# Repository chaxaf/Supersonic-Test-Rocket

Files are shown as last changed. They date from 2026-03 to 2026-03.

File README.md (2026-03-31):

# Hermes II Avionics Redesign

Semester project completed with the EPFL Rocket Team in 2022.

Hermes II is a compact avionics architecture developed for a small experimental rocket intended for validation flights and data generation. The project focused on redesigning the electronics of the original Hermes platform into a smaller, more modular system with telemetry, GPS, multiple sensor boards, and improved integration inside the rocket.

## Project summary

The avionics stack is built around one main PCB and three auxiliary PCBs placed in different parts of the rocket:

- **Main PCB** in the avionics bay
- **Nosecone PCB** for total pressure and wall temperature
- **Static port PCB** for static pressure and wall temperature
- **Load cell PCB** for thrust measurement signal conditioning

The design integrates:
- Teensy 3.5 microcontroller
- GPS
- XBee telemetry
- IMU and accelerometer
- pressure sensors
- thermocouple interfaces
- load cell instrumentation amplifier
- battery management and power regulation

## System overview

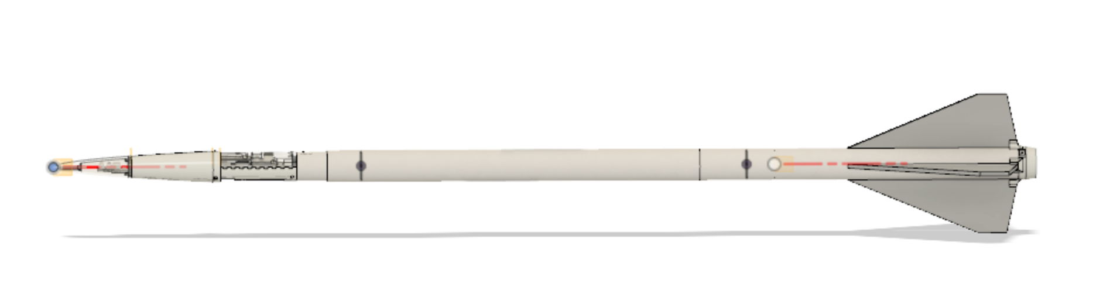
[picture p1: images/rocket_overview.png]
Rocket overview


**Source in repository:** `docs/Hermes_Presentation.pptx`

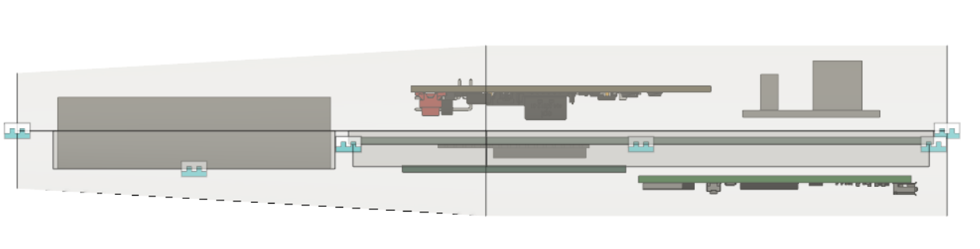
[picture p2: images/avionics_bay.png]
Avionics bay


## Main PCB

The main board had to fit inside a very constrained avionics bay while interfacing with the GPS, telemetry radio, IMU, pressure sensors, thermocouples, Altimax, Wildhorn sensor board, and auxiliary boards. It uses a 4-layer stack-up with dedicated ground and power planes.

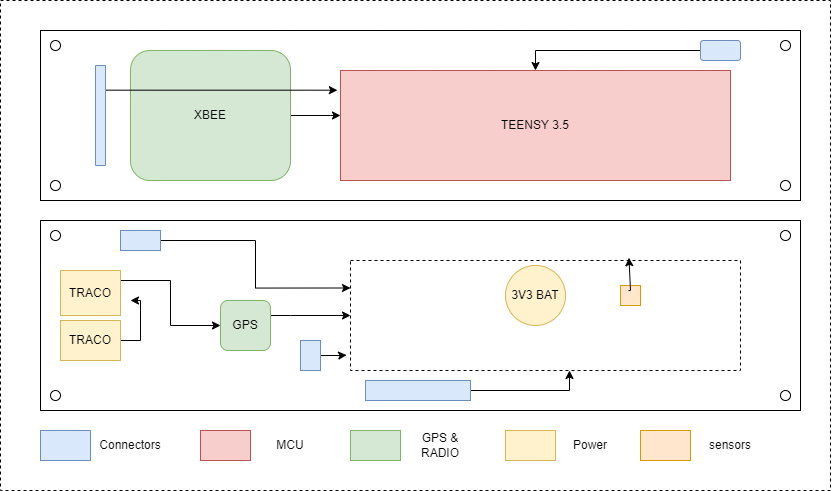
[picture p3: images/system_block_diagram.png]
System block diagram


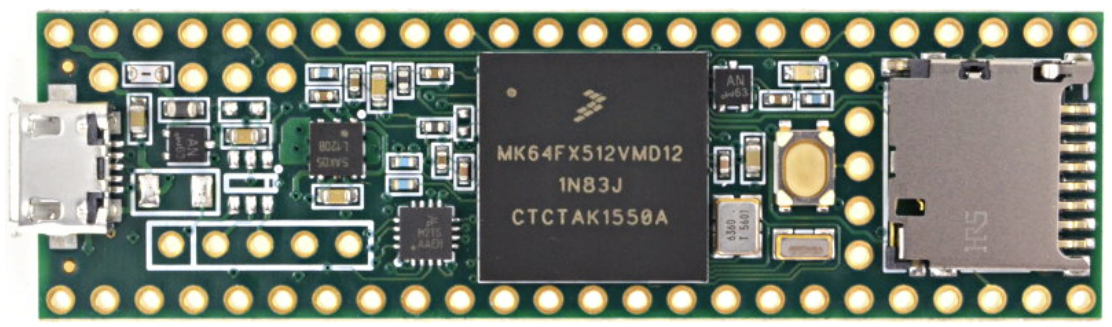
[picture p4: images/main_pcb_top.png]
Main PCB top


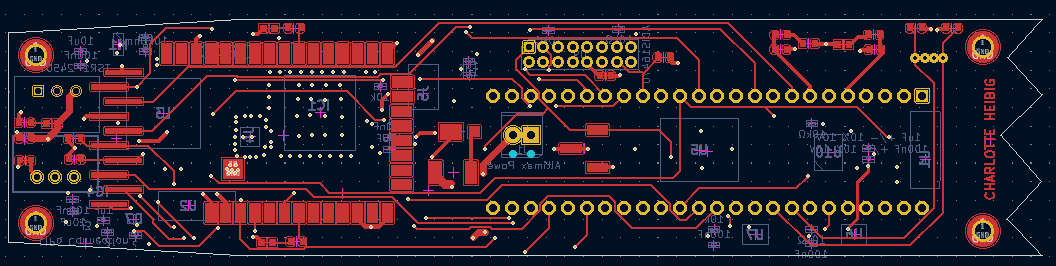
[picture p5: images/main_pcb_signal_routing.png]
Main PCB routing


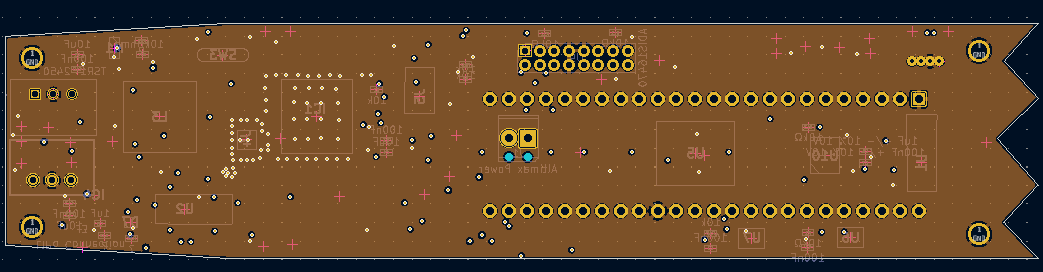
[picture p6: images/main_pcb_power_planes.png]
Main PCB power planes


## GPS layout constraints

One of the most layout-sensitive parts of the board was the GPS section, especially antenna routing and the controlled-impedance microstrip connection.

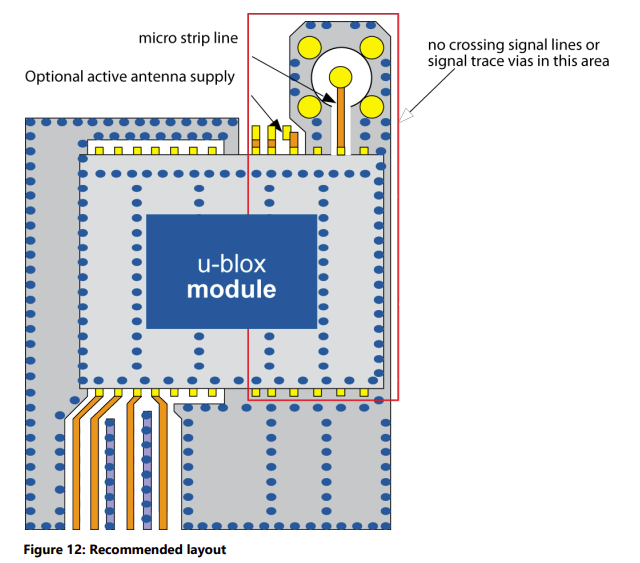
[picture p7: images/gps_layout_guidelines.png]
GPS layout


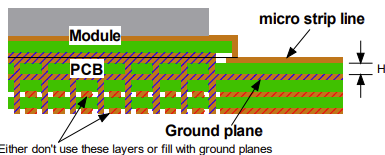
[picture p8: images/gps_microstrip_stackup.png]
GPS microstrip stackup


## Auxiliary PCBs

### Nosecone PCB
Measures total pressure and wall temperature.

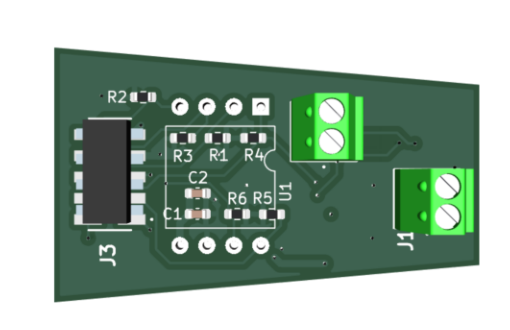
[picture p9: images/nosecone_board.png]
Nosecone PCB


### Static port PCB
Measures static pressure and wall temperature.

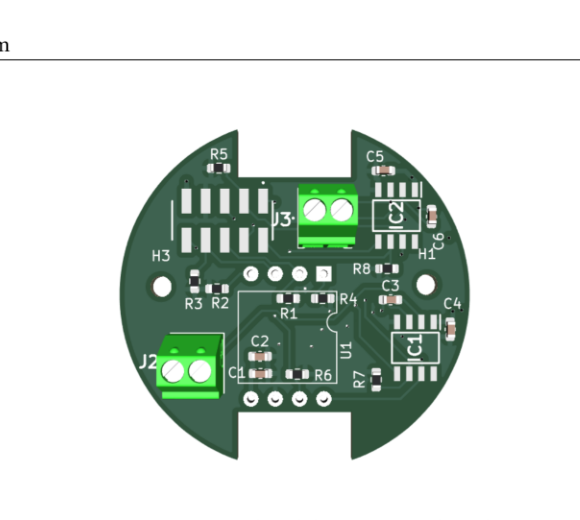
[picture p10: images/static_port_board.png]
Static port PCB


### Load cell PCB
Conditions the load cell signal used for thrust measurement.

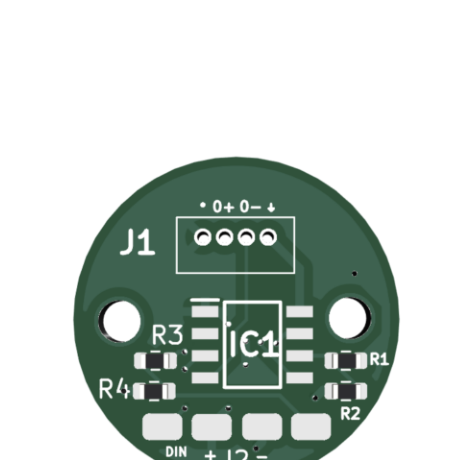
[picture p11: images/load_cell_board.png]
Load cell PCB


## Main technical points

- Compact avionics redesign for a constrained rocket airframe
- Separation of avionics into one main PCB and three auxiliary PCBs
- Integration of telemetry and GPS
- Pressure, temperature, acceleration, and inertial sensing
- Load cell instrumentation for thrust measurements
- 4-layer PCB design under mechanical, thermal, and routing constraints
- Manufacturing through a combination of external PCB assembly and manual soldering

## Results

According to the final presentation, the following subsystems were functional during project testing:

- GPS worked outdoors
- telemetry radio worked
- thermocouples worked
- pressure sensors, IMU, and Altimax were functional
- the accelerometer worked after replacing a faulty capacitor

Main issues and remaining work included:

- power supply malfunction
- some MAX31855 thermocouple interfaces failed
- connector orientation errors that were later corrected
- remaining validation work for the load cell amplifier and some Wildhorn sensor software

See slides **“RESULTATS”** and **“CONCLUSION”** in `docs/Hermes_Presentation.pptx`.

## Repository structure

```text
Hermes-II-GitHub/
├── README.md
├── .gitignore
├── docs/
│   ├── Hermes_Presentation.pptx
│   └── report.pdf
├── images/
│   ├── rocket_overview.png
│   ├── avionics_bay.png
│   ├── system_block_diagram.png
│   ├── main_pcb_top.png
│   ├── main_pcb_bottom.png
│   ├── main_pcb_signal_routing.png
│   ├── main_pcb_power_planes.png
│   ├── gps_layout_guidelines.png
│   ├── gps_microstrip_stackup.png
│   ├── nosecone_board.png
│   ├── static_port_board.png
│   └── load_cell_board.png
└── hardware/
    ├── main_pcb/
    ├── nosecone_pcb/
    ├── static_port_pcb/
    └── load_cell_pcb/
```

## Opening the hardware files

The hardware design files are provided in KiCad project format. Open the corresponding `.kicad_pro` file in each hardware subfolder.

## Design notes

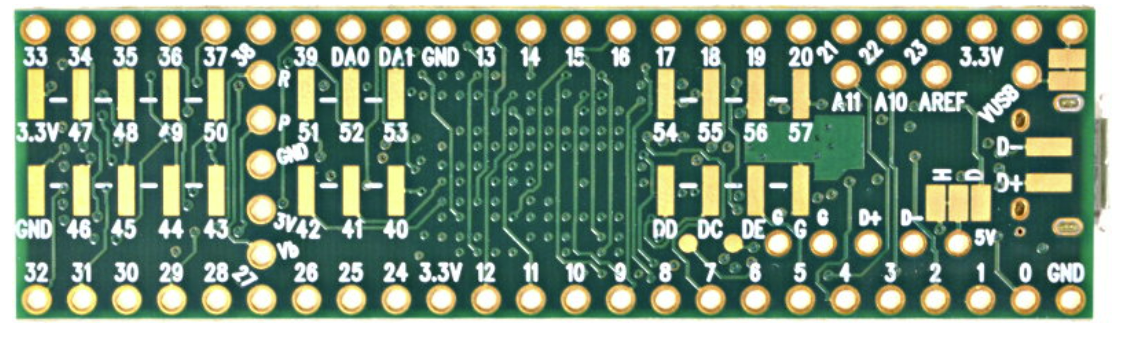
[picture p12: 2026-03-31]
images/main_pcb_bottom.png

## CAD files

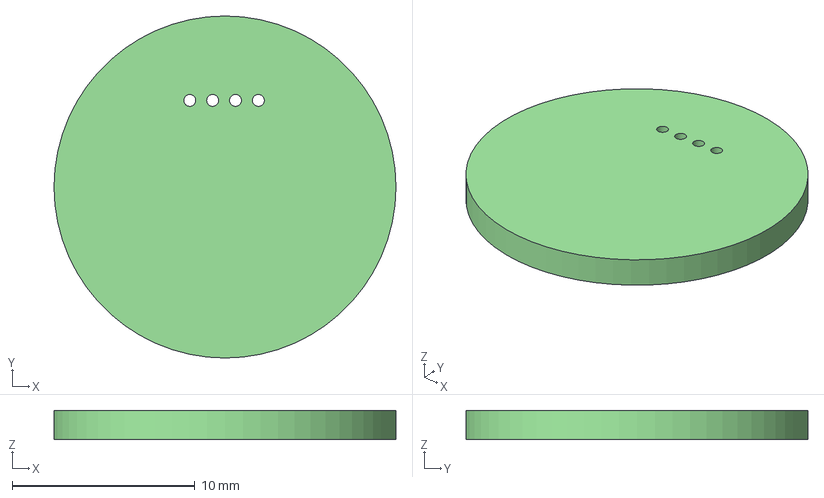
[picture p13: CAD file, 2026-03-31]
hardware/load_cell_pcb/load cell.step
18.7 x 18.7 x 1.60 mm

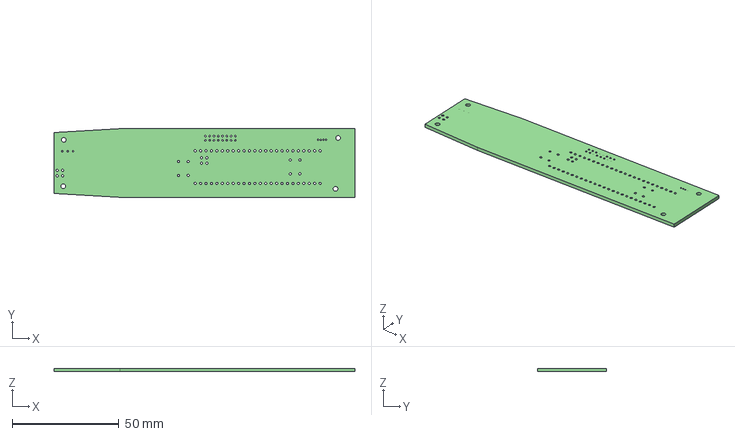
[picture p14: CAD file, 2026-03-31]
hardware/main_pcb/PCB_v1.step
140.8 x 32.1 x 1.60 mm

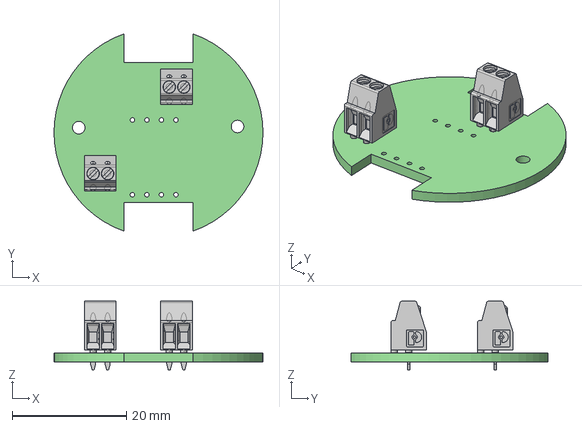
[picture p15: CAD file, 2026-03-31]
hardware/static_port_pcb/nosecone.step
36.6 x 34.6 x 12.0 mm
nosecone PCB

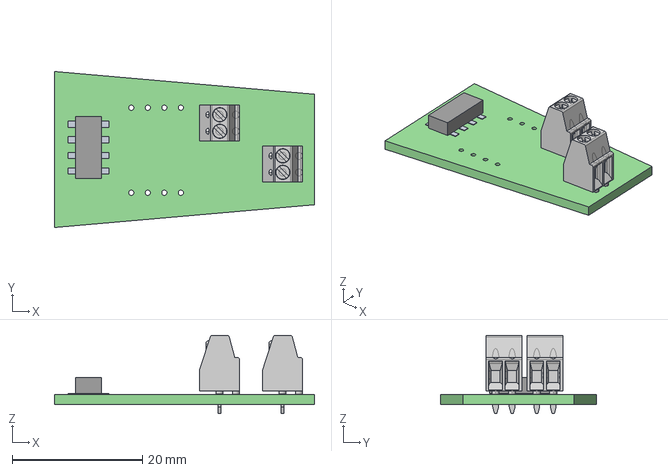
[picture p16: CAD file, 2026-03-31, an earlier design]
hardware/nosecone_pcb/nosecone.step
40.0 x 24.0 x 12.0 mm
_autosave-nosecone PCB

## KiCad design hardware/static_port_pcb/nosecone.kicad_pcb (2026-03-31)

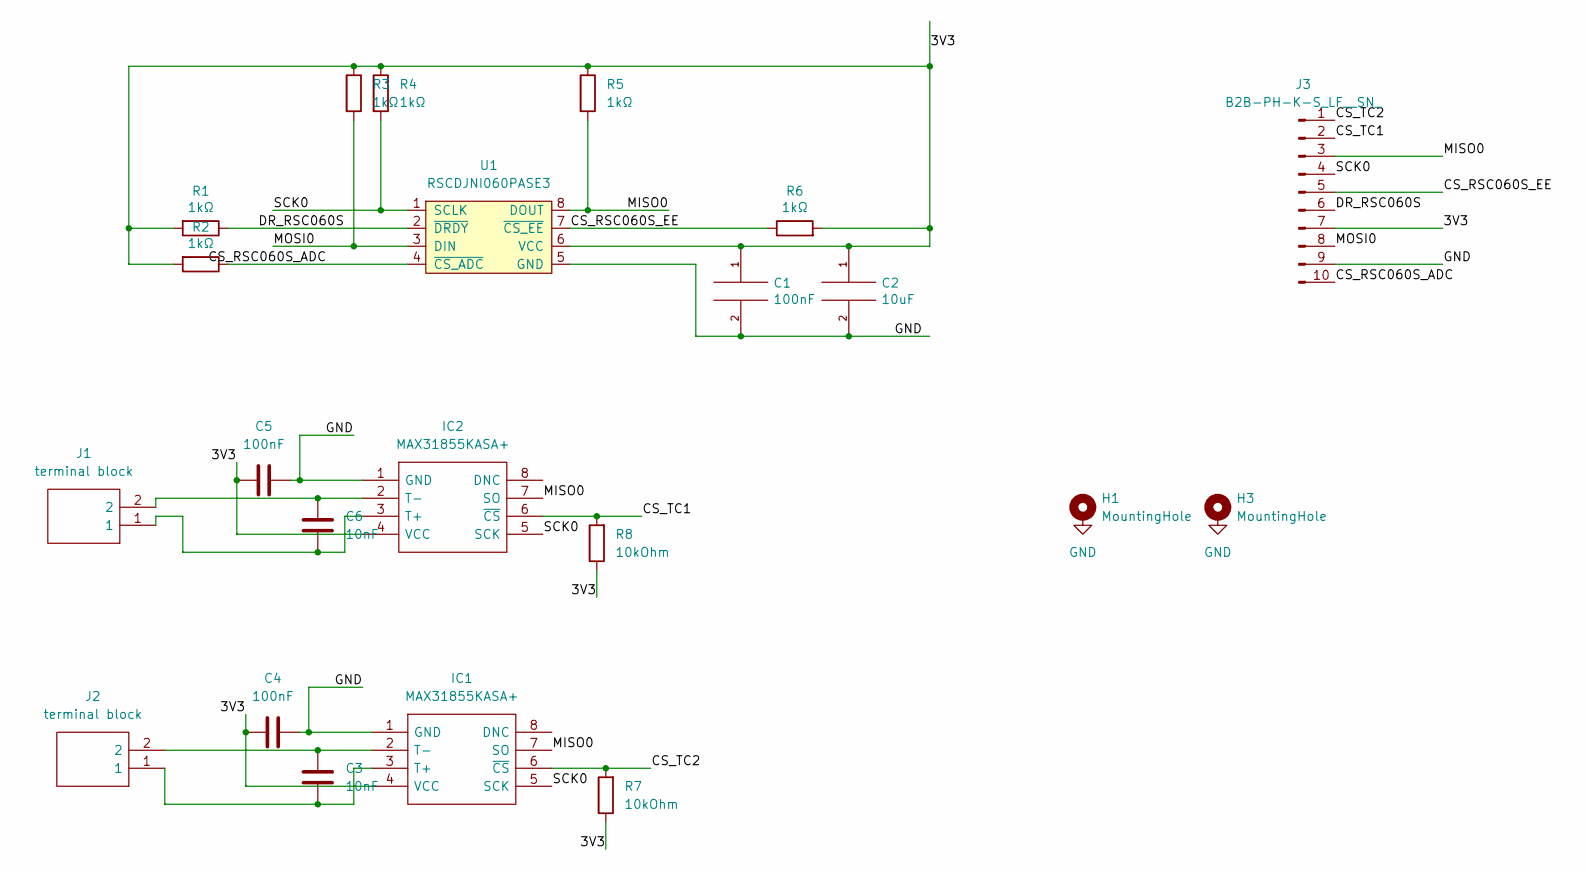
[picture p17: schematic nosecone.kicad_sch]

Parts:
C1, C4, C5: 100nF; C_0603_1608Metric
C2: 10uF; C_0603_1608Metric
C3, C6: 10nF; C_0603_1608Metric
H1, H3: MountingHole; MountingHole_2.2mm_M2
IC1, IC2: MAX31855KASA+; SOIC127P600X175-8N; Manufacturer_Part_Number MAX31855KASA+; Mouser Part Number 700-MAX31855KASA+
J1, J2: terminal block; Manufacturer_Part_Number 1725656; Mouser Part Number 651-1725656
J3: B2B-PH-K-S_LF__SN_; 57202G5205LF
R1, R2, R3, R4, R5, R6: 1kΩ; R_0603_1608Metric
R7, R8: 10kOhm; R_0603_1608Metric
U1: RSCDJNI060PASE3; DIP-8_W13.08mm

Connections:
/3V3: C1.1, C2.1, C4.2, C5.2, IC1.4 (VCC), IC2.4 (VCC), J3.7, R1.2, R2.2, R3.1, R4.1, R5.1, R6.2, R7.1, R8.1, U1.6 (VCC)
/CS_RSC060S_ADC: J3.10, R2.1, U1.4 (~CS_ADC)
/CS_RSC060S_EE: J3.5, R6.1, U1.7 (~CS_EE)
/CS_TC1: IC2.6 (~CS), J3.2, R8.2
/CS_TC2: IC1.6 (~CS), J3.1, R7.2
/DR_RSC060S: J3.6, R1.1, U1.2 (~DRDY)
/MISO0: IC1.7 (SO), IC2.7 (SO), J3.3, R5.2, U1.8 (DOUT)
/MOSI0: J3.8, R3.2, U1.3 (DIN)
/SCK0: IC1.5 (SCK), IC2.5 (SCK), J3.4, R4.2, U1.1 (SCLK)
GND: C1.2, C2.2, C4.1, C5.1, IC1.1 (GND), IC2.1 (GND), J3.9, U1.5 (GND)
unnamed: C3.1, IC1.3 (T+), J2.1
unnamed: C3.2, IC1.2 (T-), J2.2
unnamed: C6.1, IC2.3 (T+), J1.1
unnamed: C6.2, IC2.2 (T-), J1.2

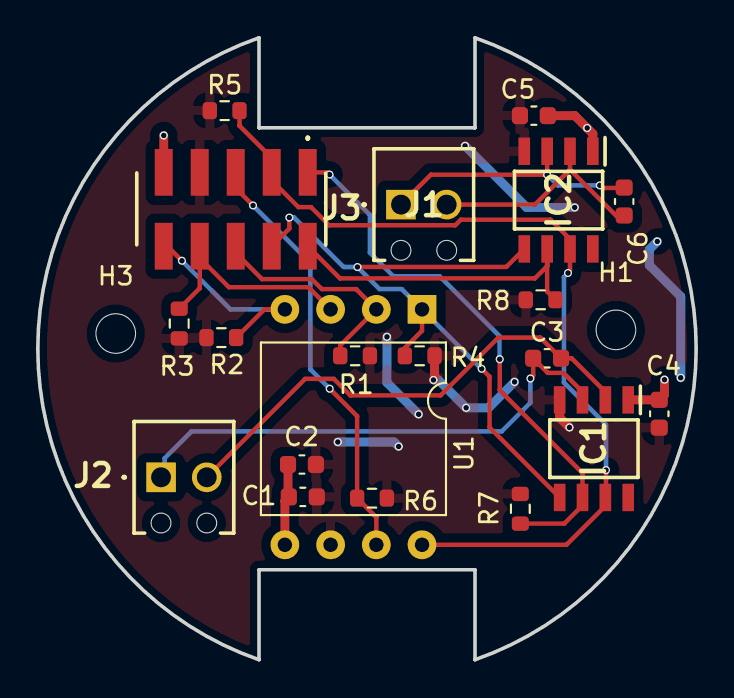
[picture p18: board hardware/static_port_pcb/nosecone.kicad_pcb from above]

Board: 2 copper layers, 36.6 x 34.6 mm, 22 parts (0 on the bottom side), 14 nets.

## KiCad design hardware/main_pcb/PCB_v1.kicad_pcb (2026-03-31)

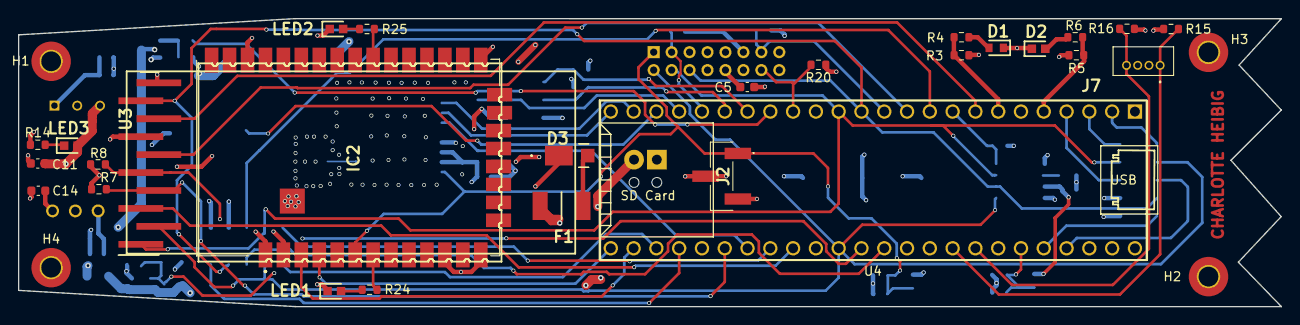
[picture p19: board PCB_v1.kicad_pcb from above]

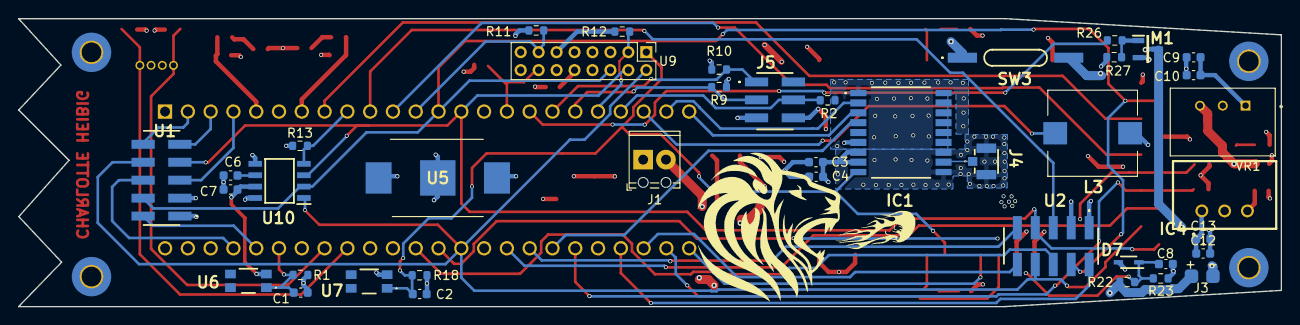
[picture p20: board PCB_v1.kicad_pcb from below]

Board: 4 copper layers, 140.8 x 32.1 mm, 72 parts (41 on the bottom side), 57 nets.

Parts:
C1, C2, C3, C5, C10, C11, C13, C14: 100nF; C_0603_1608Metric
C4, C9, C12: 10uF; C_0603_1608Metric
C6: 1uF +/- 10% 10V; C_0603_1608Metric
C7: 100nF +/- 10% 10V; C_0603_1608Metric
C8: 1uF; C_0603_1608Metric
D1: White LED; LEDC1608X45N
D2: Red LED; LEDC1608X80N
D3: D_Schottky; V8PAN50M3I
D7: BZX584C3V3-G3-08; SOD2513X110N
F1: MINIASMDC150F_12-2; MINISMDC050F2
H1, H2, H3, H4: Board_Hole; MountingHole_2.2mm_M2_Pad_TopBottom
IC1: MAX-7C-0; MAX7C0
IC2: XB8X-DMUS-001; XBP9XDMRS001
IC4: TSR_0.5-2433; TSR-0.5-2433
J1: Altimax Power; TerminalBlock_Phoenix_MPT-0,5-2-2.54_1x02_P2.54mm_Horizontal
J2: 0878980304
J3: LiPo Connection; pad2
J4: CONUFL001-SMD-T; CONUFL001-SMD
J5: 57202G5203LF
J7: 1734598-4; 17345984
L3: SMI-1027-T-5V-R; SMI1027T5VR
LED1, LED2, LED3: 150060GS75000; LEDC1608X80N
M1: MNMOS; SOT95P237X112-3N
R1, R4, R6, R11, R12, R13, R20: 10kΩ; R_0603_1608Metric
R2, R9, R10, R15, R16, R18: 10k; R_0603_1608Metric
R3: 100Ω; R_0603_1608Metric
R5: 24Ω; R_0603_1608Metric
R7, R8, R27: 10kOhm; R_0603_1608Metric
R14: 10K; R_0603_1608Metric
R22, R23: ?; R_0603_1608Metric
R24, R25: 24; R_0603_1608Metric
R26: R; R_0603_1608Metric
SW3: MISM7R610
U1, U2: 57202G5205LF
U3: 1-2842102-0; HUSRSP10W50P200_2000X200X550P
U4: Teensy3.5; Teensy35_36_exterior_pins_only
U5: 3030
U6, U7: switch; RKC2SJF170SMTRLFS
U9: ADIS16470; PinHeader_2x08_P2.00mm_Vertical
U10: AIS1120SXTR; SOIC127P600X175-8N
VR1: TSR1-2450; CONV_TSR1-2450

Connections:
+3V3: C2.1, C3.1, C4.1, C5.1, C7.1, C14.1, IC1.7 (VCC_IO), IC1.8 (VCC), IC2.2 (VCC), IC4.3 (+VOUT), J5.6, R7.1, R8.1, R12.1, R13.1, R15.2, R16.2, R18.1, U1.3, U2.3, U3.7, U6.3, U9.10 (VDD), U9.11 (VDD), U9.12 (VDD), U10.7 (VDD)
+5V: C11.1, C12.1, C13.1, IC4.1 (+VIN), J7.3, LED3.2, U4.53 (Vin), VR1.3 (+VOUT)
/MISO0: U1.7, U2.7, U3.1, U4.14 (12_MISO0), U9.4 (DOUT), U10.3 (SDO)
/MOSI0: U1.4, U2.4, U3.9, U4.13 (11_MOSI0), U9.6 (DIN), U10.2 (SDI)
/RTC_supply: IC1.6 (V_BCKP), J2.2, U5.1, U5.3
/SCK0: U1.8, U2.8, U3.2, U4.40 (13_SCK0_LED), U9.2 (SCLK), U10.1 (SCL)
/aux1: J5.3, R9.2, U4.19 (27_RX1_SCK0)
/aux2: J5.1, R10.2, U4.18 (26_TX1_SCL2)
/aux3: J5.4, R2.1, U4.21 (29_PWM_CAN0TX_Touch)
/bat_voltage: C8.2, D7.1, R22.2, R23.1, U4.41 (14_A0_PWM_SCK0)
/button1: C1.1, R1.1, U4.48 (21_A7_PWM_CS0_MOSI1), U6.1
/buzzer_input: L3.1, U4.22 (30_PWM_CAN0RX_Touch)
/cs_acc: R13.2, U4.9 (7_RX3_MOSI0_SCL0), U10.4 (CS)
/cs_adis: R12.2, U4.20 (28_MOSI0), U9.3 (CS)
/cs_pressure_adc_1: U1.2, U4.49 (22_A8_PWM_Touch)
/cs_pressure_adc_2: U2.2, U4.33 (36_A17_PWM)
/cs_pressure_ee_1: U1.5, U4.4 (2_PWM)
/cs_pressure_ee_2: U2.5, U4.10 (8_TX3_MISO0_SDA0)
/cs_tc1: U1.9, U4.3 (1_TX1_MISO1_Touch)
/cs_tc2: U1.10, U4.2 (0_RX1_MOSI1_Touch)
/cs_tc3: U2.9, U4.37 (A21_DAC0)
/cs_tc4: U2.10, U4.32 (35_A16_PWM)
/dr_adis: R11.2, U4.12 (10_PWM_TX2_CS0), U9.13 (DR)
/dr_pressure_1: U1.6, U4.50 (23_A9_PWM_Touch)
/dr_pressure_2: U2.6, U4.42 (15_A1_CS0_Touch)
/enable_gnd: R26.1, U4.17 (25)
/gp0_spi: U3.3, U4.38 (A22_DAC1)
/gp3_spi: U3.8, U4.8 (6_PWM)
/gp4_spi: U3.6, U4.11 (9_PWM_RX2_CS0)
/led1: R3.2, R4.1, U4.7 (5_PWM_TX1_MISO1)
/led2: R5.1, R6.2, U4.5 (3_PWM_CAN0TX_SCL2)
/load_minus: J7.1, R15.1, U4.45 (18_A4_SDA0_Touch)
/load_plus: J7.4, R16.1, U4.46 (19_A5_SCL0_Touch)
/nReset: C2.2, IC1.9 (RESET_N), IC2.6 (~RESET), J2.1, R18.2, U7.1, U9.1 (RST)
/rx_ublox: IC1.3 (RXD), U4.24 (32_A13_TX4_SCK1)
/rx_xbee: IC2.4 (DIN/DIO14/~CONFIG), U4.30 (33_A14_TX5_CAN1TX_SCL0)
/scl_i2c: R8.2, U3.5, U4.34 (37_A18_PWM_SCL1)
/sda_i2c: R7.2, U3.4, U4.35 (38_A19_PWM_SDA1)
/sync_adis: R20.2, U4.16 (24), U9.14 (SYNC)
/timepulse_ublox: IC1.4 (TIMEPULSE), U4.36 (39_A20)
/tx_ublox: IC1.2 (TXD), U4.23 (31_A12_RX4_CS1)
/tx_xbee: IC2.3 (DIO13/DOUT), U4.31 (34_A15_RX5_CAN1RX_SDA0)
GND: C1.2, C3.2, C4.2, C5.2, C6.2, C7.2, C8.1, C9.2, C10.2, C11.2, C12.2, C13.2, C14.2, D1.1 (K), D2.1 (K), D7.2, H1.1, H2.1, H3.1, H4.1, IC1.1 (GND_1), IC1.10 (GND_2), IC1.12 (GND_3), IC2.1 (GND_1), IC2.11 (GND_2), IC2.13 (GND_3), IC2.22 (GND_4), IC2.35 (GND_5), IC2.38 (GND_6), IC4.2 (GND), J2.3, J4.2 (GND_1), J4.3 (GND_2), J5.5, J7.2, L3.2, LED1.1, LED2.1, M1.2 (S), R1.2, R2.2, R4.2, R6.1, R9.1, R10.1, R11.1, R14.2, R20.1, R23.2, R27.2, SW3.1 (A), U1.1, U2.1, U3.10, U4.1 (GND), U4.39 (GND), U5.2, U7.3, U9.7 (GND), U9.8 (GND), U9.9 (GND), U10.5 (GND), U10.8 (MP), VR1.2 (GND)
unnamed: C6.1, U10.6 (VREG)
unnamed: C9.1, C10.1, D3.1 (K), VR1.1 (+VIN)
unnamed: D1.2 (A), R3.1
unnamed: D2.2 (A), R5.2
unnamed: D3.2 (A), F1.2
unnamed: F1.1, J1.2, J3.2, R22.1
unnamed: IC1.11 (RF_IN), J4.1 (SIG)
unnamed: IC2.7 (DIO10/RSSI/PWM0), R24.1
unnamed: IC2.28 (DIO5/ASSOC), R25.2
unnamed: J1.1, J3.1, M1.1 (D), SW3.2 (B)
unnamed: LED1.2, R24.2
unnamed: LED2.2, R25.1
unnamed: LED3.1, R14.1
unnamed: M1.3 (G), R26.2, R27.1

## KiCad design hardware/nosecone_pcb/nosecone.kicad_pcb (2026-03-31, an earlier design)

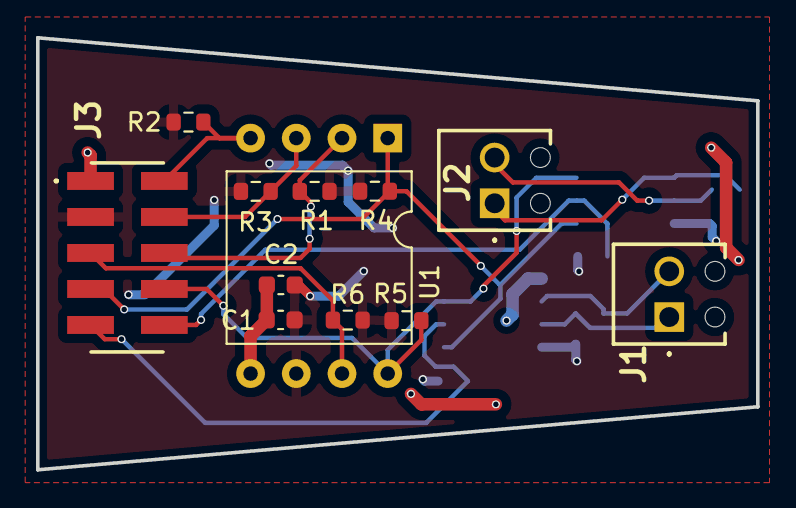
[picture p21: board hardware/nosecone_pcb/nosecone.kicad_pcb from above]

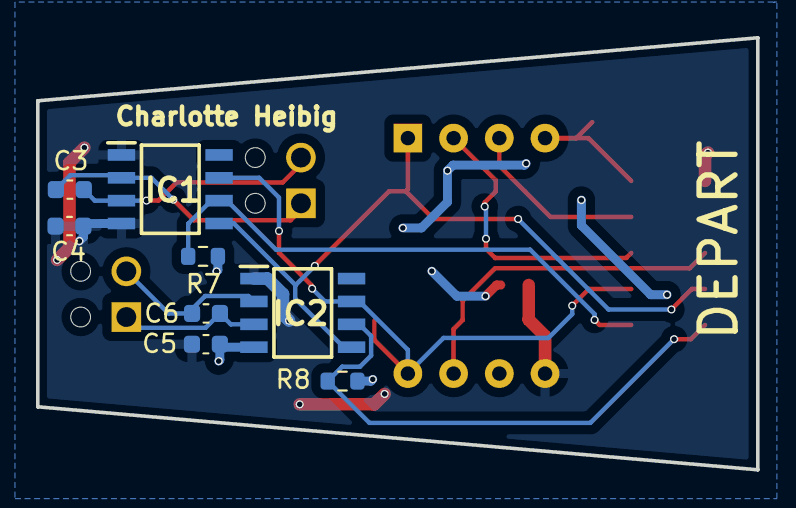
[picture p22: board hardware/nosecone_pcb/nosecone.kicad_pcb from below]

Board: 2 copper layers, 40.0 x 24.0 mm, 20 parts (8 on the bottom side), 14 nets.

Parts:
C1, C4, C5: 100nF; C_0603_1608Metric
C2: 10uF; C_0603_1608Metric
C3, C6: 10nF; C_0603_1608Metric
IC1, IC2: MAX31855KASA+; SOIC127P600X175-8N
J1, J2: 1725656
J3: B2B-PH-K-S_LF__SN_; 57202G5205LF
R1, R2, R3, R4, R5, R6: 1kΩ; R_0603_1608Metric
R7, R8: 10kOhm; R_0603_1608Metric
U1: RSCDJNI060PASE3; DIP-8_W13.08mm

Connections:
/3V3: C1.1, C2.1, C5.2, IC2.4 (VCC), J3.3, R1.2, R2.2, R3.1, R4.1, R5.1, R6.2, R7.1, R8.1, U1.6 (VCC)
/CS_RSC060S_ADC: J3.2, R2.1, U1.4 (~CS_ADC)
/CS_RSC060S_EE: J3.5, R6.1, U1.7 (~CS_EE)
/CS_TC3: IC2.6 (~CS), J3.9, R8.2
/CS_TC4: IC1.6 (~CS), J3.10, R7.2
/DR_RSC060S: J3.6, R1.1, U1.2 (~DRDY)
/GND: C1.2, C2.2, C4.1, C4.2, C5.1, IC1.1 (GND), IC1.4 (VCC), IC2.1 (GND), J3.1, U1.5 (GND)
/MISO0: IC1.7 (SO), IC2.7 (SO), J3.8, R5.2, U1.8 (DOUT)
/MOSI0: J3.4, R3.2, U1.3 (DIN)
/SCK0: IC1.5 (SCK), IC2.5 (SCK), J3.7, R4.2, U1.1 (SCLK)
unnamed: C3.1, IC1.3 (T+), J2.2
unnamed: C3.2, IC1.2 (T-), J2.1
unnamed: C6.1, IC2.3 (T+), J1.1
unnamed: C6.2, IC2.2 (T-), J1.2

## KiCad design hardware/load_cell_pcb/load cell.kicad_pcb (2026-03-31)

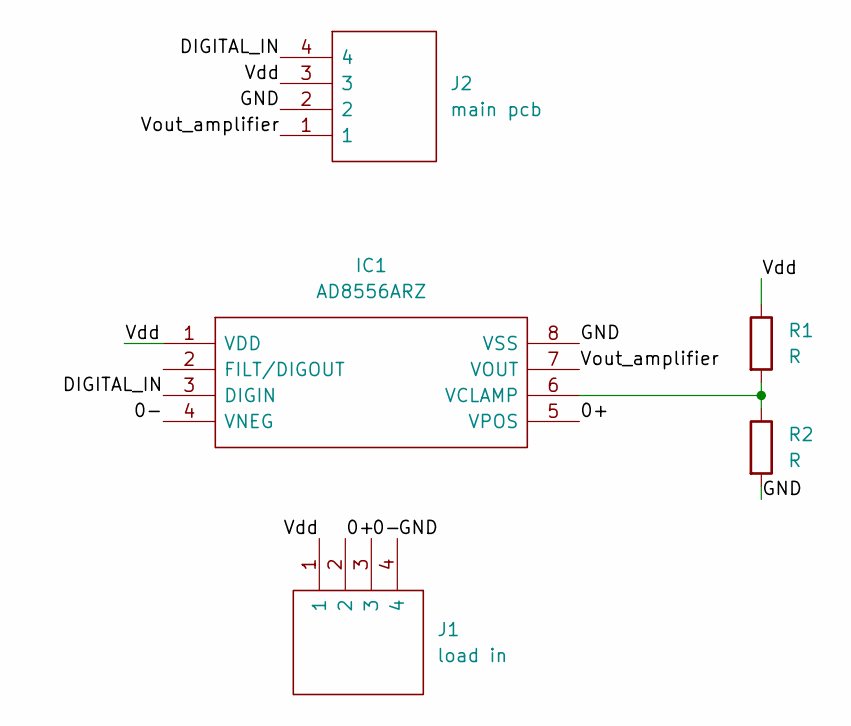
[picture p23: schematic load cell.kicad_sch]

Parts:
IC1: AD8556ARZ; SOIC127P600X175-8N; Manufacturer_Part_Number AD8556ARZ; Mouser Part Number 584-AD8556ARZ
J1: load in; 17345984; Manufacturer_Part_Number 1734598-4; Mouser Part Number 571-1734598-4
J2: main pcb; load to main; Manufacturer_Part_Number 1734598-4; Mouser Part Number 571-1734598-4
R1, R2: R; R_0603_1608Metric

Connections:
/0+: IC1.5 (VPOS), J1.2
/0-: IC1.4 (VNEG), J1.3
/DIGITAL_IN: IC1.3 (DIGIN), J2.4
/GND: IC1.8 (VSS), J1.4, J2.2, R2.2
/Vdd: IC1.1 (VDD), J1.1, J2.3, R1.1
/Vout_amplifier: IC1.7 (VOUT), J2.1
unnamed: IC1.6 (VCLAMP), R1.2, R2.1

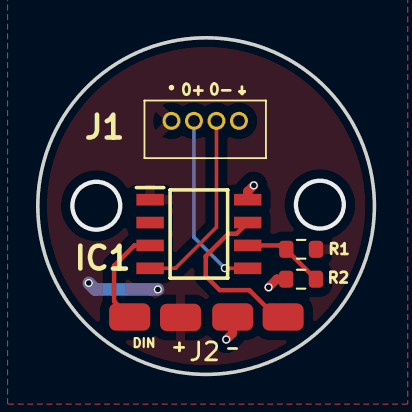
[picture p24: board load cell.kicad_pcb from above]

Board: 2 copper layers, 18.7 x 18.7 mm, 5 parts (0 on the bottom side), 7 nets.
